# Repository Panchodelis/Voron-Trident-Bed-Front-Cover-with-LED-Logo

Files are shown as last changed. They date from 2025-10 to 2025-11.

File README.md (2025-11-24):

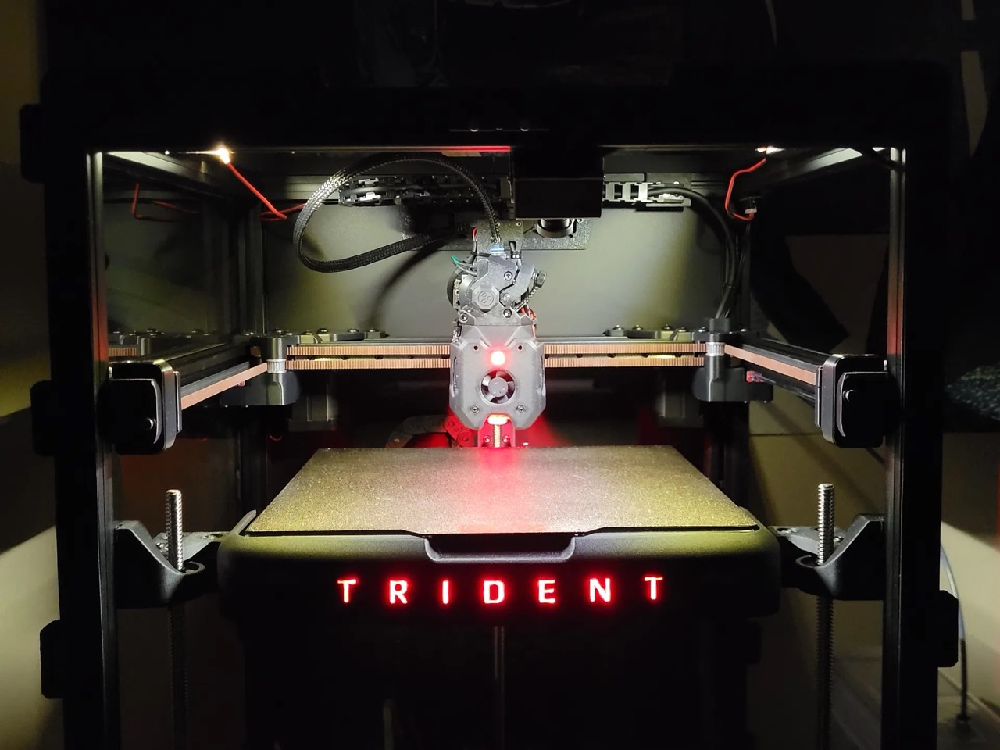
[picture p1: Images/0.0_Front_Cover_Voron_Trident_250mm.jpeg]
Voron Trident Bed Front Cover


## 🧠 Features
- Illuminated "Trident" logo using two internal LED strips.
- Easy to install and remove.
- Can slightly help maintain **bed temperature stability** when printing with **open doors** or in **cooler environments**.
- ⚠️⚠️⚠️ Designed for a Voron Trident 250 mm with a 10 mm aluminum build plate (LDO kit).  
  Other configurations (e.g., 8 mm plate or 300 mm and 350mm machines) are untested.  
  I will update compatibility as users report results — feedback appreciated!

## ✅ Tested Configurations

| Configuration | Status | Notes |
|---|:---:|---|
| Trident 250 mm — 10 mm plate | ✅ | Tested and confirmed |
| Trident 250 mm — 8 mm plate | ❓ | Awaiting community testing |
| Trident 300 mm — 10 mm plate | ❓ | Awaiting community testing |
| Trident 300 mm — 8 mm plate | ❓ | Awaiting community testing |
| Trident 350 mm — 10 mm plate | ❓ | Awaiting community testing |
| Trident 350 mm — 8 mm plate | ❓ | Awaiting community testing |

## 📦 Download the Models

All STL files are available on **Printables**:

👉 [🔗 Voron Trident Bed Front Cover with LED Logo – Printables]([https://www.printables.com/@Panchodelis](https://www.printables.com/model/1452981-voron-trident-bed-front-cover-with-led-logo)

---

## 🧩 Alternate Version — Blank Front for Custom Designs

In addition to the illuminated “Triden” logo version, this project also includes a **blank variant** of the front cover assembly.  
This version contains **all structural and mounting parts**, maintaining the same LED backlighting concept with diffuser integration — but **without any logo or cutouts**.

It is intended as a **template for customized designs**, allowing you to adapt the front cover to feature:
- A different illuminated logo  
- A status light bar  
- Or any other LED-based front design you’d like to experiment with  

The included **blank LED diffuser** is flat, with no raised lettering.  
You can modify both the **front cover** and **diffuser** to include your own logo or pattern — simply extrude your design into the diffuser and cut matching openings in the front cover.

🧠 **Tip:**  
If you prefer a clean front without any logo or lighting, you can simply print **parts #1 (Front Cover)** and **#4 (Front Cover Holder)** available on Printables.  
These two parts form a solid decorative cover without the LED system.

💡 **Recommendation for remixers:**  
If you plan to create your own illuminated design, it’s recommended to review the **CAD file of the logo version** first.  
Understanding the internal structure and the LED diffuser concept will likely save you time and failed test prints.
---

## 🧩 Print Settings

This design consists of **seven printed parts**:

1. **Mounting structure** – supports the frontal assembly.  
2. **Front cover** – main visible part with the illuminated “Triden” logo.  
3. **LED diffuser** – translucent insert for the logo.  
4. **LED and wiring support** – holds the LED strips and manages cable routing.  
5. **Rear cover** – blocks any light escaping through the convection vent holes.  
6. **Letter “D”** – printed separately for proper detail.  
7. **Letter “R”** – printed separately for proper detail.

---

### ⚙️ Materials

All parts except the diffuser should be printed in **ASA-CF** or **ABS-GF** ensure high heat resistance and dimensional stability.  
ASA-CF softens around **110 °C**, making it suitable for components close to the heated bed.  
It also offers a premium matte finish and reduced warping compared to standard ASA or ABS.

The **LED diffuser** is printed in **translucent PETG**, which provides smooth light transmission and is easy to post-process.

Other materials such as **ASA**, **ABS**, or **PETG-CF** can be considered as alternatives depending on availability and enclosure temperature control.  
Before selecting an alternative, always check the **glass transition temperature (Tg)** of the material and keep a **safety margin below your normal bed temperature** to prevent softening or deformation during operation.

There is a **minimum clearance of approximately 3.5 mm** between the aluminum bed plate and the front cover.  
This gap allows a **column of cool air** to rise naturally between both surfaces, reducing **thermal radiation coupling** from the bed to the printed part by an estimated **20–30 %**, depending on ambient conditions.

---

| Setting | Recommended Value |
|---|---|
| Material | ASA-CF/ABS-GF/ASA/ABS/PETG-CF for all parts except LED diffuser (PETG translucent) |
| Layer Height | Optional (depends on desired finish) |
| Infill | 20–40 % |
| Supports | Required (see notes below) |
| Orientation | Logo facing up for main parts / letters facing up for diffuser |

---

### 🧠 Important Notes

#### 🧱 Front Cover
- Pay **special attention to the “N” letter** — part of it prints directly on the support surface.  
  Verify in your slicer preview that sufficient support is generated below this area.  
- The **“E” letter** also requires proper supports; without them, it may collapse during printing.  
- For the **“D” and “R” letters**, print them separately and maintain the **same orientation** as the front cover for consistent layer direction and surface texture.  
- Use **manually painted supports** for the logo area and **tree supports** for the letters to achieve cleaner results and easier removal.

#### 💡 LED Diffuser
- Print **flat with the letters facing upward**, using **automatic supports**.  
- Avoid overly dense supports to simplify cleanup after printing.

---

### 🛠️ Slicing tolerances

- **Main panel slot tolerance:** +0.05 mm  
- **LED diffuser contour tolerance:** −0.10 mm  
- If the diffuser doesn’t fit easily, try **−0.15 mm** for a looser fit.

After printing, minor cleanup of the letters may be needed to remove support residue and ensure a precise fit of the PETG diffuser.

## 📦 Bill of Materials (BOM)

| # | Item | Specification / Notes | Quantity |
|---|---|---|---|
| 1 | **Mounting structure** | Printed part (ASA-CF) | 1 |
| 2 | **Front cover** | Printed part (ASA-CF) | 1 |
| 3 | **LED diffuser** | Printed part (translucent PETG) | 1 |
| 4 | **LED and wiring support** | Printed part (ASA-CF) | 1 |
| 5 | **Rear cover** | Printed part (ASA-CF) | 1 |
| 6 | **Letter "D"** | Printed part (ASA-CF) | 1 |
| 7 | **Letter "R"** | Printed part (ASA-CF) | 1 |
| 8 | **LED strips** | 24 V LED strip, **5 mm width**, **red color**, SMD 2835 type | 2 |
| 9 | **M3 socket head screws (8 mm)** | ISO 7380 or DIN 912 | 4 |
| 10 | **M3 socket head screws (14 mm)** | ISO 7380 or DIN 912 | 7 |
| 11 | **M3 T-nuts** | Compatible with 2020 aluminum extrusion | 3 |
| 12 | **M3 threaded inserts** | Standard Voron brass heat inserts Ø5 mm outer diameter | 8 |
| 13 | **Wire (24 V rated)** | Red/black, silicone insulated | As needed |
| 14 | **Power connectors (DC jack)** | 2-conductor 24 V DC barrel connectors — **1 male + 1 inline female (non-panel type)** | 2 |
| 15 | **JST connector (for MCU)** | **JST 3-pin** (for fan port on Leviathan or similar board) – use matching type for your MCU port | 1 |
| 16 | **Cable sleeve or heat shrink** | For neat cable routing | As needed |

---

### 💡 Notes
- The LED channels are designed for **5 mm wide strips**, which **slide into dedicated guide rails** — no adhesive required.  
- The design allows for easy removal or replacement of LED strips for maintenance.  
- LED strips are **24 V SMD 2835 red**, compatible with fan ports on the **MCU Board**.  
- If your board provides **5 V** instead of 24 V, use a **5 V LED strip** of the same 5 mm width.  
- Power is routed through a **pair of DC jack connectors (male + female)** for quick disconnection.  
- Ensure the LED circuit is **fused** or connected through a **switched 24 V rail**.  
- The **rear cover is optional** — light bleed through the convection vents will depend on LED brightness.  
  For reference, the LEDs in the reference build run at **~10 % intensity** from a **24 V fan port**, resulting in minimal light leakage and balanced illumination.

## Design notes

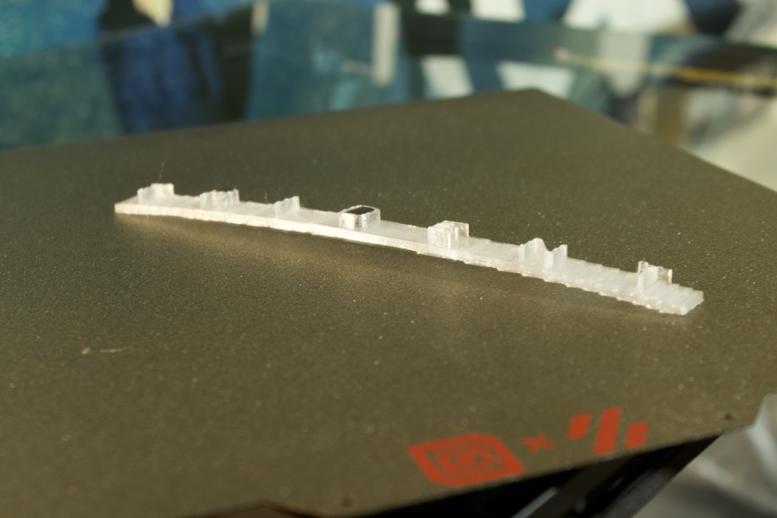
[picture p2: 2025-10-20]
Images/3.2-Led_diffuser_2.jpeg

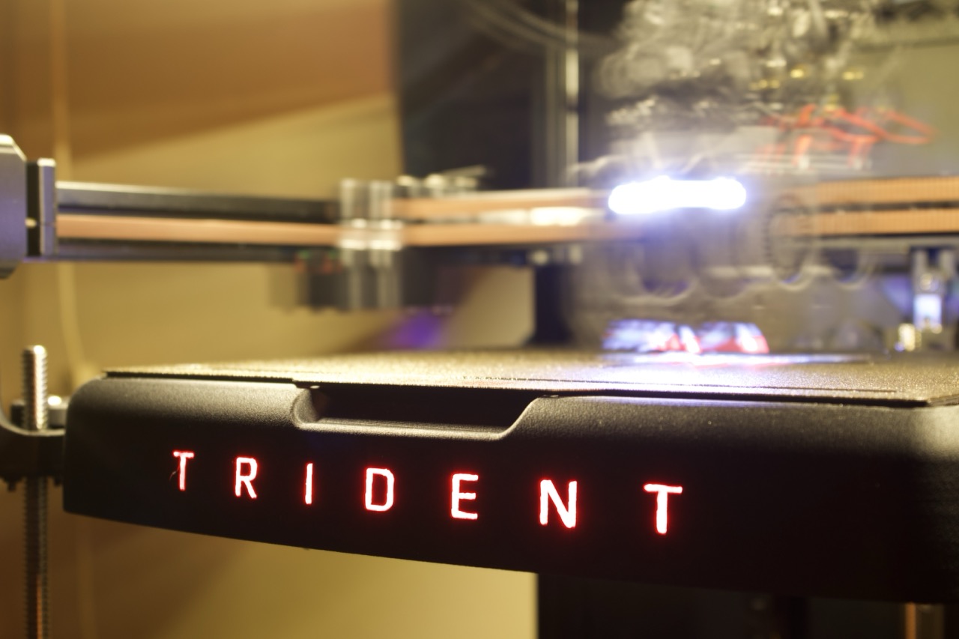
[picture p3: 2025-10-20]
Images/0.0-VT_bed_front_cover_final.jpeg

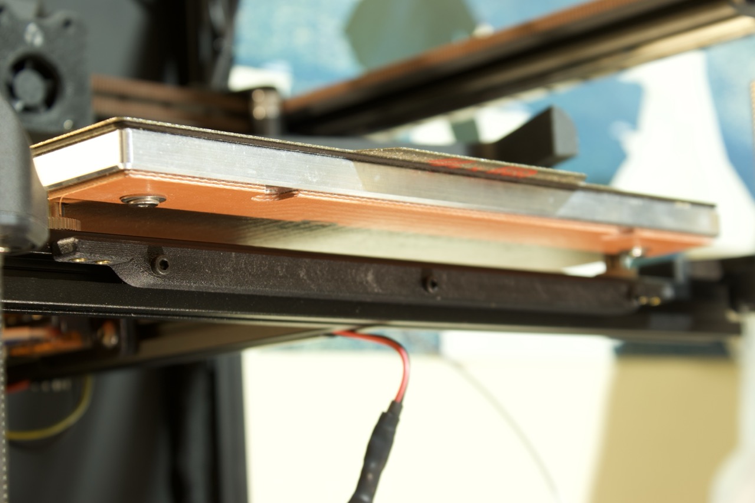
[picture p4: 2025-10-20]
Images/1.3-Mounting structure.jpeg

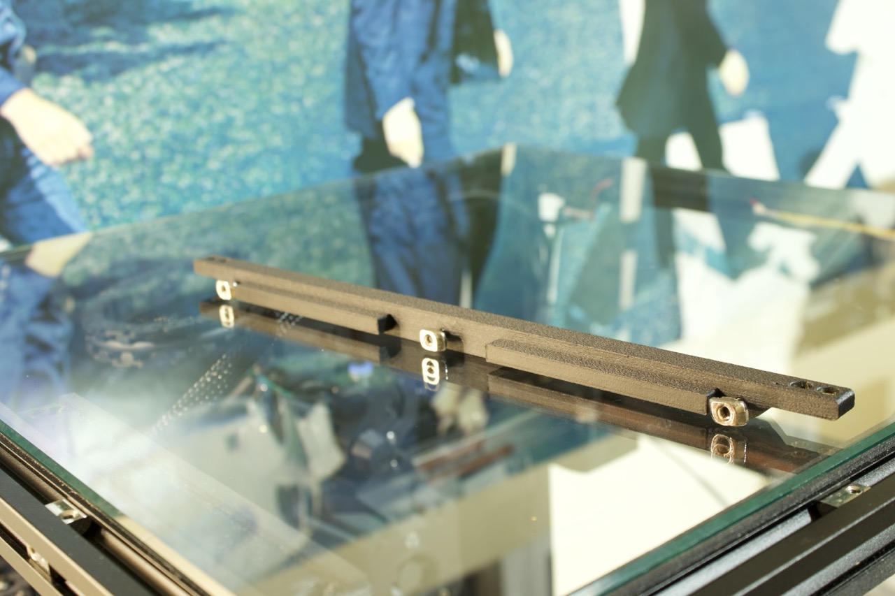
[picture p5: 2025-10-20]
Images/1.1-Mounting_structure_2.jpeg

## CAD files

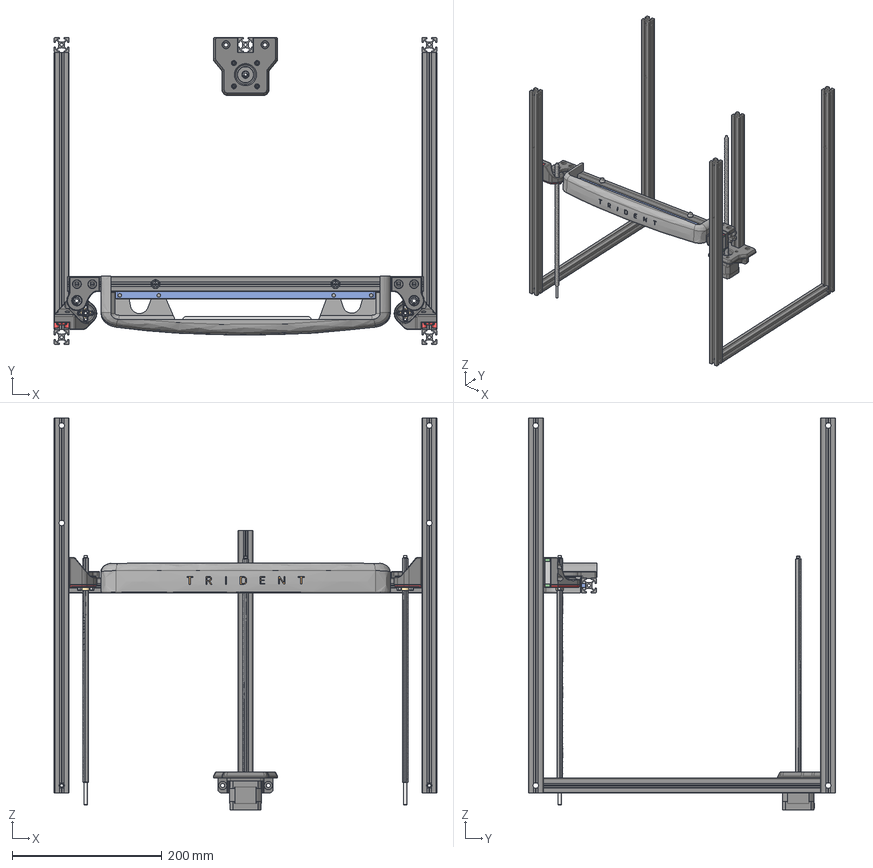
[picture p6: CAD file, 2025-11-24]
CAD/VT350mm_Plate10mm.step
510.7 x 410.0 x 522.6 mm

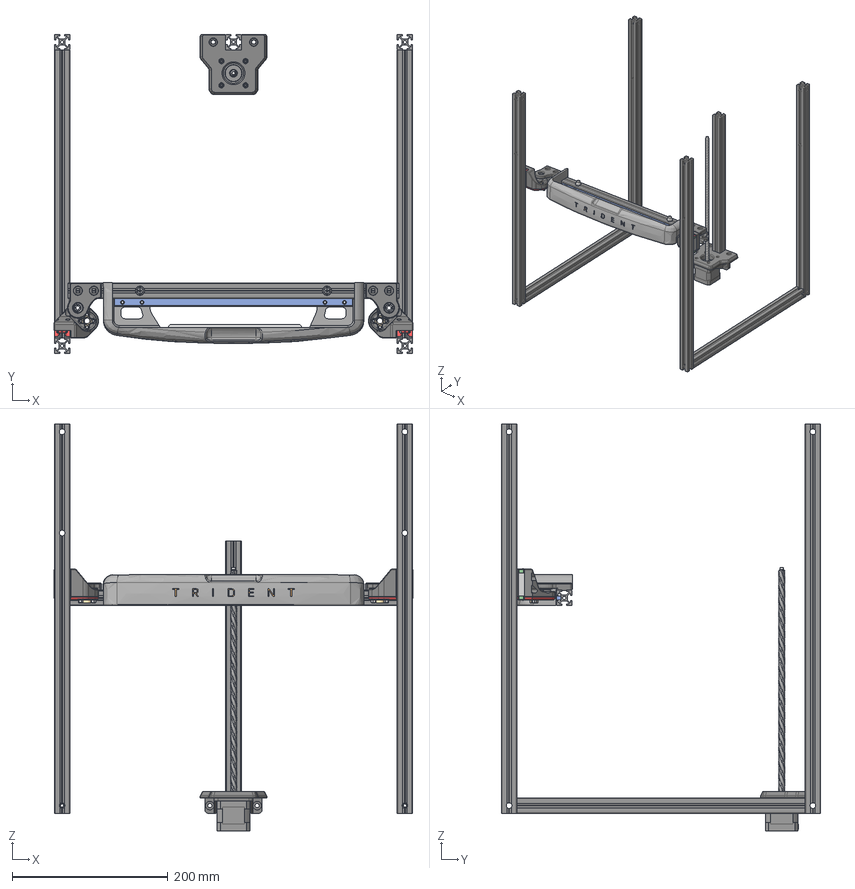
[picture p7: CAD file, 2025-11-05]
CAD/VT300mm_Plate10mm.step
460.7 x 410.0 x 522.6 mm

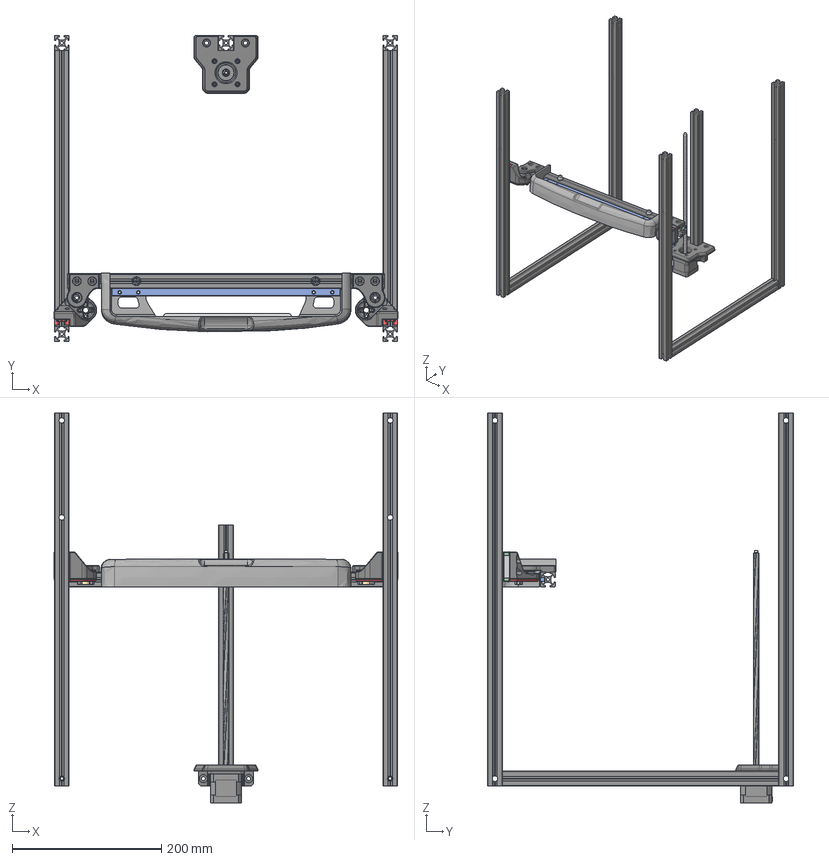
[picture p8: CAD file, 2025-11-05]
CAD/VT300mm_Plate8mm Without Logo.step
460.7 x 410.0 x 522.6 mm

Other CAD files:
CAD/VT350mm_Plate10mm Without Logo.step
CAD/VT350mm_Plate8mm.step
CAD/VT350mm_Plate8mm_WithoutLogo.step
CAD/VT300mm_Plate10mm Without Logo.step
CAD/VT300mm_Plate8mm.step

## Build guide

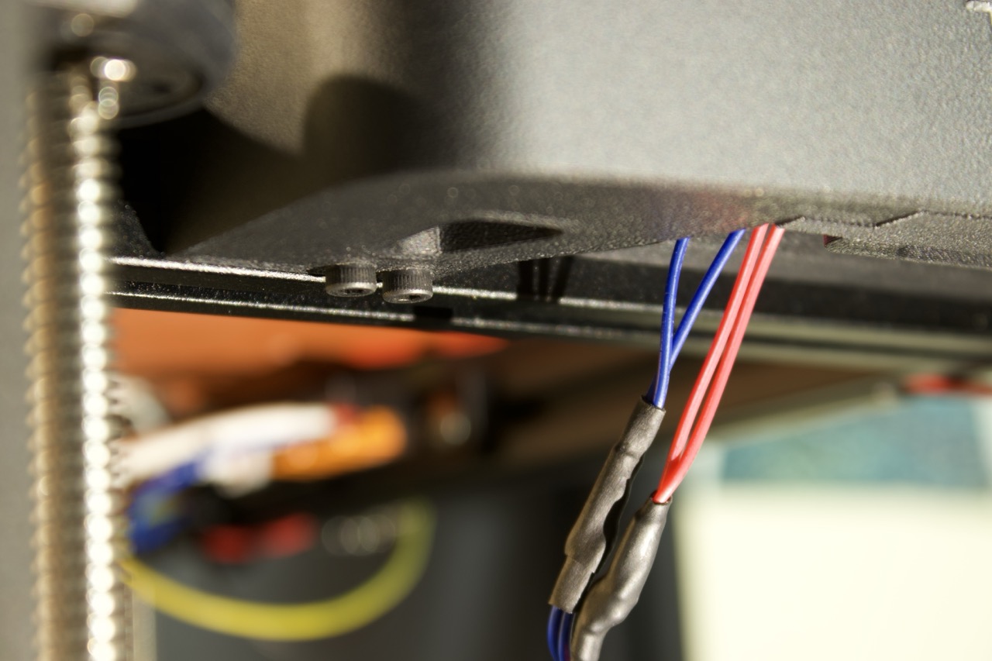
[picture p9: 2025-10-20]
Images/Mounting_screws_complete_front_assembly.jpeg

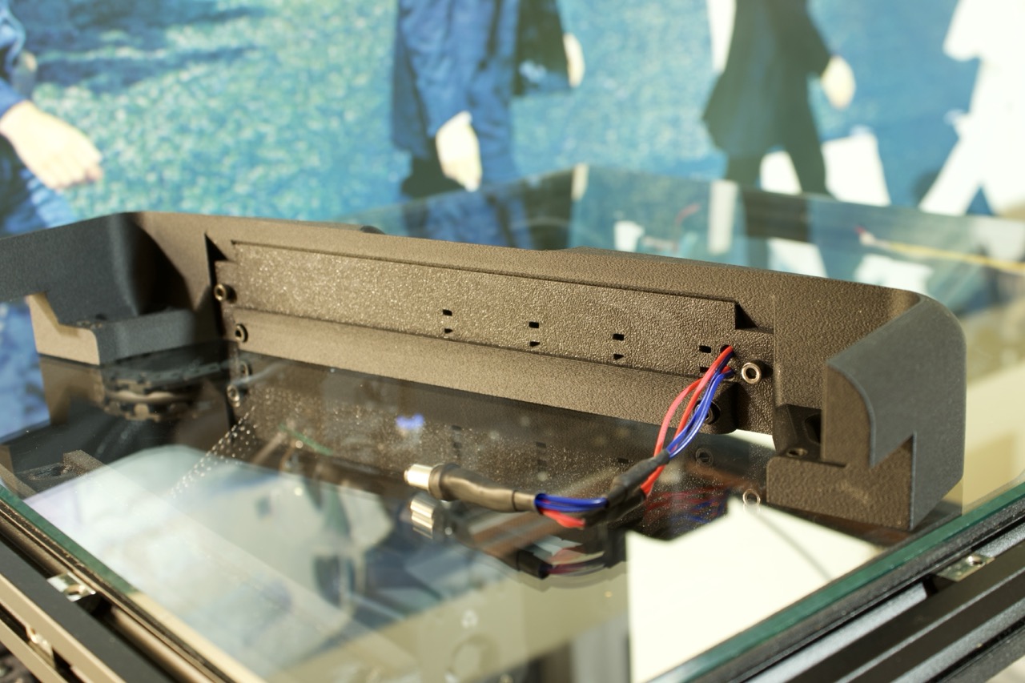
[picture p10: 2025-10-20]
Images/5.3-Led_and_wiring_support_with_cover_assembly.jpeg

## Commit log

2025-10-20 Create BOM
2025-10-20 Update BOM
2025-10-21 Rename 0.Support extrusion.jpeg to 1.Support extrusion.jpeg
2025-10-21 Add download section for model files
    Added download section with link to Printables for STL and STEP files.
2025-10-21 Add image to README for Voron Trident Bed
2025-10-22 Fix formatting issue in BOM file
2025-10-22 Update compatibility note for LED strips
2025-10-22 Remove bed temperature stability feature
    Removed a feature about improving bed temperature stability.
2025-10-22 Update README with bed temperature stability info
    Added note about bed temperature stability during printing.
2025-10-23 Revise material specifications in README
    Updated material recommendations for printing parts, specifying both ASA-CF and ABS-GF for heat resistance. Adjusted softening temperature and removed mention of ABS-GF in alternatives.
2025-10-26 Update README with 8 mm bed plate compatibility
    Added information about compatibility with 8 mm aluminum bed plates and requested feedback on testing.
2025-10-26 Document alternate version of front cover assembly
    Added details about an alternate blank front cover version for custom designs, including its features and printing tips.
2025-11-05 Rename 0.0 Front Cover Voron Trident 250mm.jpg to 0.0 Front_Cover_Voron_Trident_250mm.jpg
